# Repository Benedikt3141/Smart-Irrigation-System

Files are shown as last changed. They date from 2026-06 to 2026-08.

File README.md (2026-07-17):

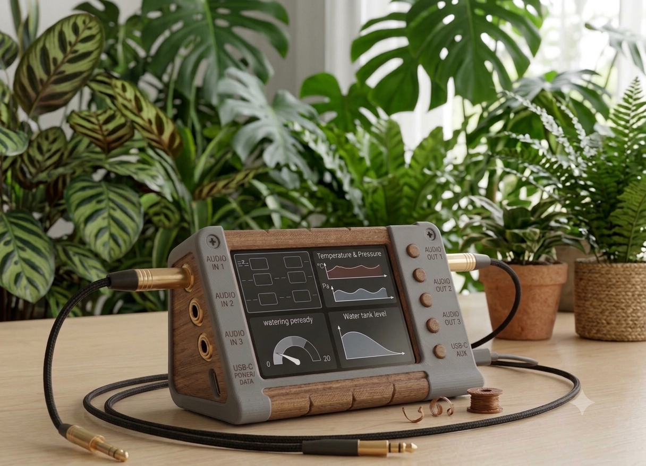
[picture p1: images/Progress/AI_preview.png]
AIPreview


-> AI Preview

# Smart Irrigation System

The Smart Irrigation System is a battery-powered monitoring and control system for watering up to six individual plants.
Each plant is monitored by a capacitive soil moisture sensor connected to the main control unit.

The project currently focuses on the main monitoring and control unit. A separate watering unit is planned but not fully designed yet. Communication between both units is intended to use ESP-NOW.

## Project Overview

The system consists of two main parts:

### Main Monitoring and Control Unit

The main unit collects sensor data, displays current measurements on a TFT screen, logs data to an SD card and indicates the system status using an LED strip.

Each soil moisture sensor is connected individually using an audio jack connector.

### Watering Unit

The watering unit is planned as a separate module. It will receive commands from the main control unit via ESP-NOW and control the water flow using a solenoid valve.
The unit should also monitor the water tank level using an ultrasonic sensor.

This part of the system is still work in progress.

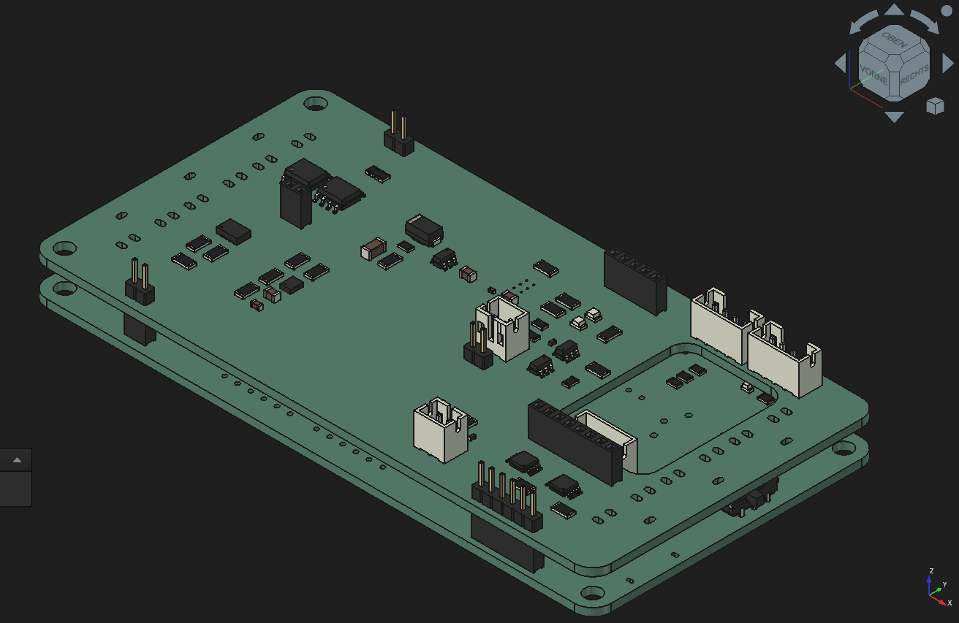
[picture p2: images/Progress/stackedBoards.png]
stackedBoards


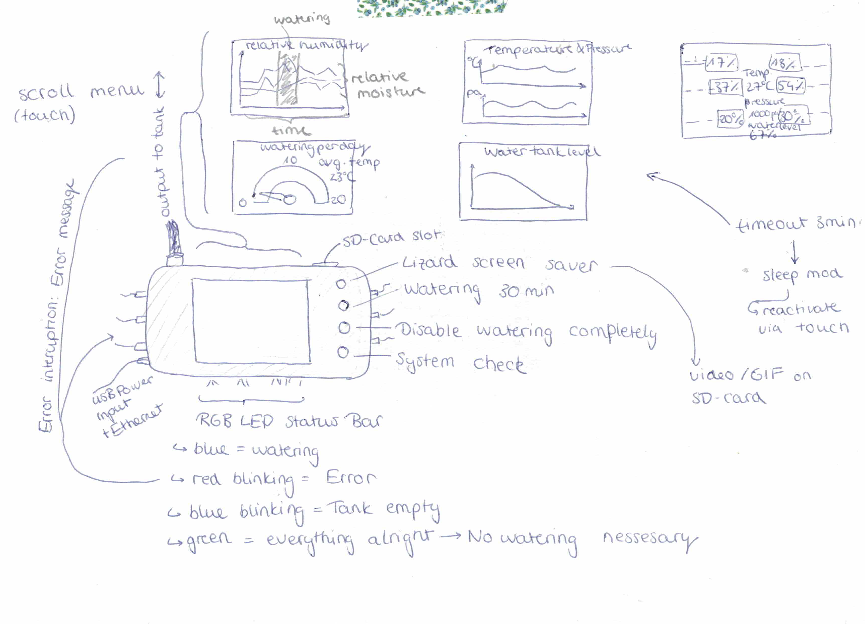
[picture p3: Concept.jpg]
Concept


## Feature overview

###### Sensors (Inputs)

- **Soil mositure monitoring** for individual plants
- **Temperature**
- Humidity
- Air pressure
- Air Quality
- CO2 concentration
- Solar intensity
- 4 Buttons
- *Tank fill state sensor*

###### Other features and outputs

- **Battery powered**
- 2.4" TFT LCD Screen with resistive touch
- SD log with data saved as .csv
- LED-Strip status indicator
- magnetic valve for watering Control
- *web interface*
- *Push Emails when water is empty/error etc.*

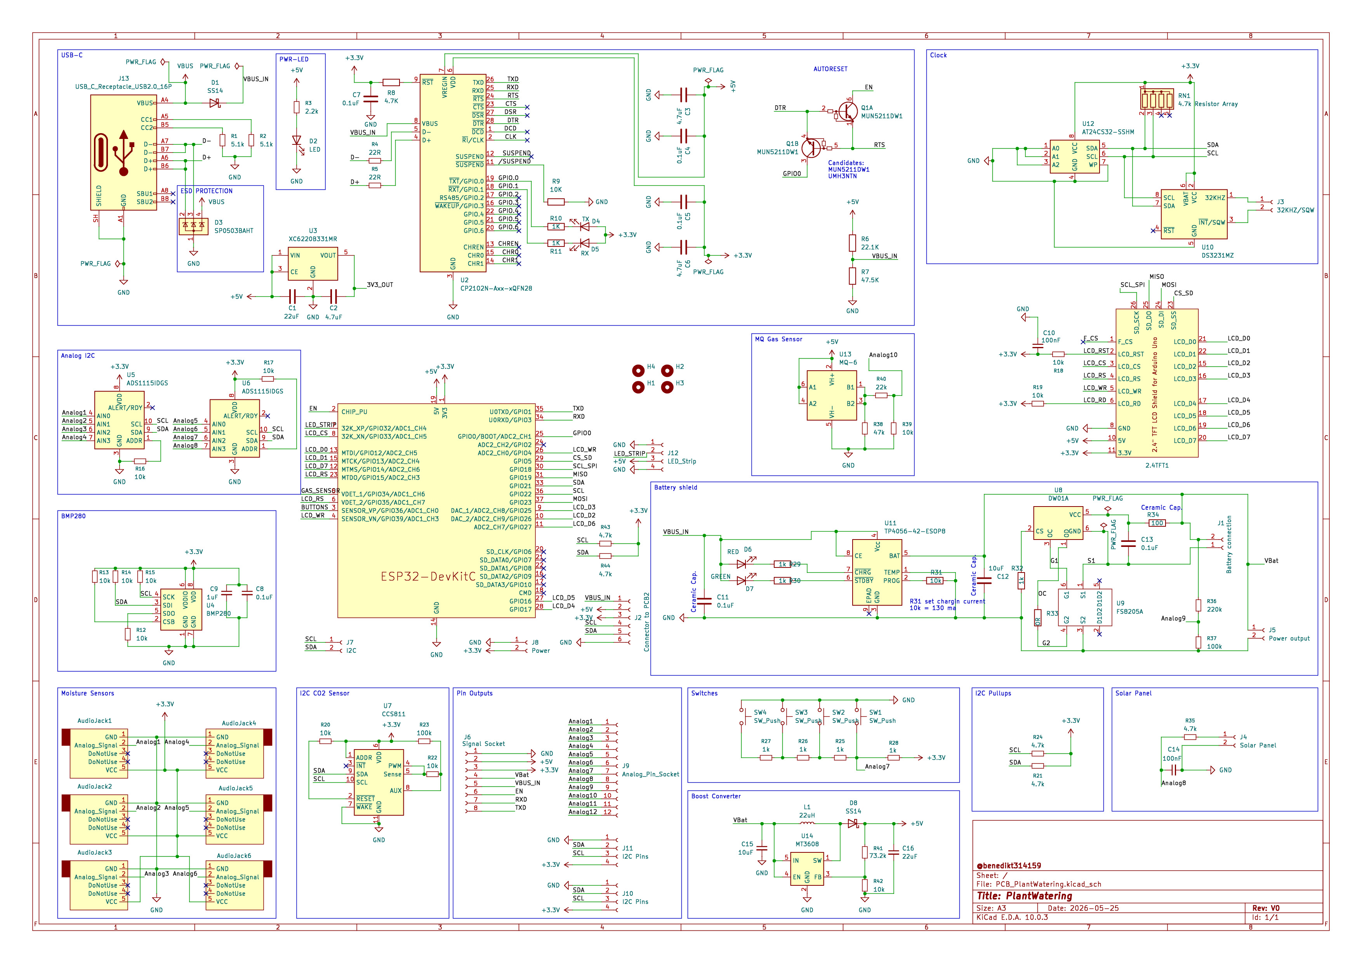
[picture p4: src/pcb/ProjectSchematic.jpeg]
Schematic


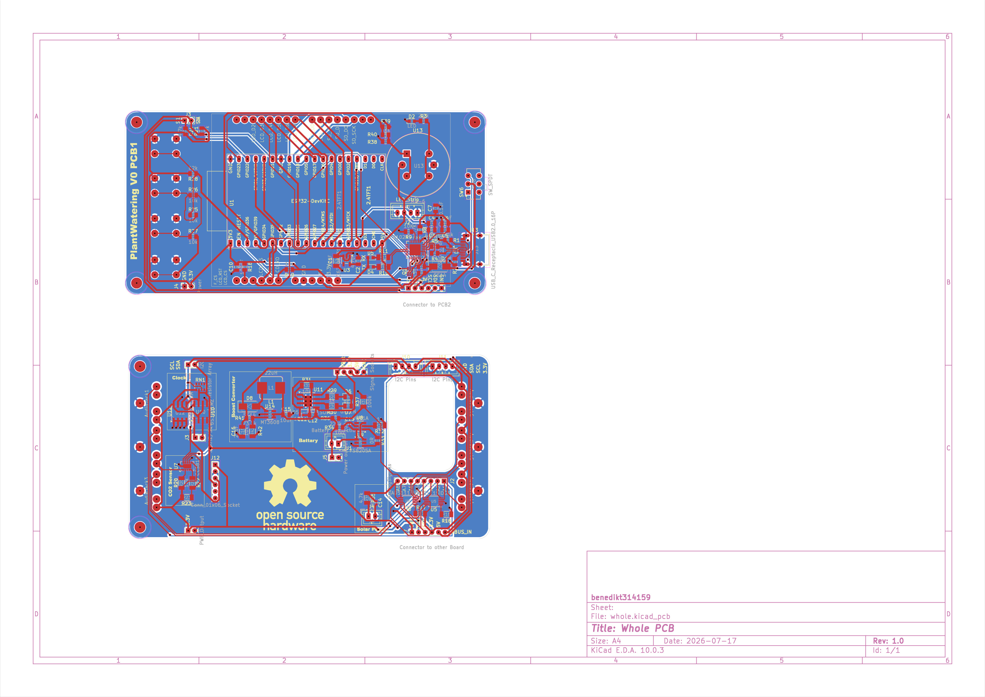
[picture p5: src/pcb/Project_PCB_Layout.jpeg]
PCB


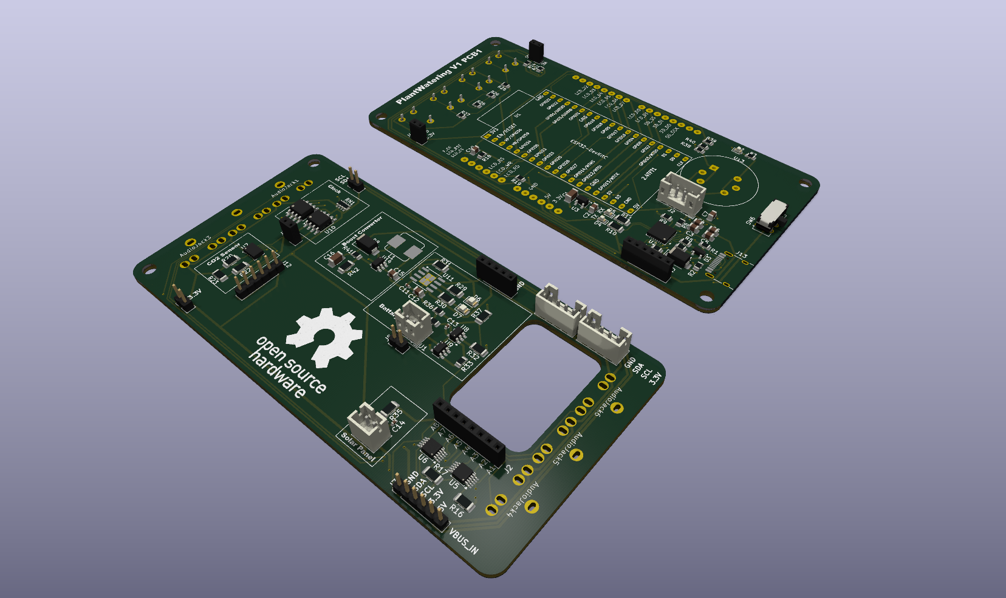
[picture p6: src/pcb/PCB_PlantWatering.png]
Rendering


## Repository Structure

This repository contains both the firmware and the PCB design files.

- `/firmware/` contains the PlatformIO firmware project.
- `/firmware/src/` contains the ESP32 source code.
- `/src/pcb/` contains the KiCad PCB design files.
- `/src/pcb/gerbers/` contains the exported Gerber files for manufacturing.

The main monitoring and control unit consists of two stacked custom PCBs. Both PCBs are part of the same project and are required for the complete device.

## File Structure

```
Smart-Irrigation-System/
├── BOM.csv
├── JOURNAL.md
├── README.md
├── firmware/
│   ├── platformio.ini
│   └── src/
├── src/
│   ├── assembly_and_models/
│   │   ├── SmartIrrigationSystem-Assembly.step
│   │   └── SmartIrrigationSystem.FCStd
│   └── pcb/
│       ├── PlantWatering_PCB01/
│       ├── PlantWatering_PCB02/
│       └── gerbers/
└── images/
```

## Getting started

#### Requirements

To work with this project, you need:

* VS Code
* PlatformIO or pioarduino IDE Extension
* C++ Compiler
* KiCad 10.0.1 or later

#### Installation

Use git to clone this repository into your computer.

```
git clone https://github.com/Benedikt3141/Smart-Irrigation-System.git
```

Open the project folder in VS Code and build/upload the firmware using PlatformIO or pioarduino.

###### Hardware

You can either use the provided Gerber files or modify the KiCad project and generate new manufacturing files for your preferred PCB supplier.

You can find the gerberfiles [here (PCB01)](src/pcb/PlantWatering_PCB01/production) and [here (PCB02)](src/pcb/PlantWatering_PCB02/production)) or in the project root. The correlating `BOM.csv` and `position.csv` can be found in the same directories.

## License

[MIT](https://choosealicense.com/licenses/mit/)

## Current Project Status

This project is still in development.

The main monitoring unit is mostly implemented. The watering unit, web interface and notification system are planned but not finished yet.

## Sources

[MQ2 Library](https://github.com/labay11/MQ-2-sensor-library/)
[SD Card](https://RandomNerdTutorials.com/esp32-web-server-microsd-card/)

## AI Usage

Most of the code was written by myself. Since this is a work in progress, the code may still contain bugs or parts that could be improved.

I used AI for debugging assistance, spelling correction, research and for generating the concept visualization shown at the top of this README.

The visualization is intended only as a preview of the planned device and
does not represent the final manufactured hardware.

The PCB design, hardware architecture and most of the firmware were
created by myself.

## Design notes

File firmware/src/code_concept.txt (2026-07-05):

setup {
    selfcheck <-- Output auf Display
        initialization and startup of all objects
            Display
            SD Card
            Soil moisture
            etc. 
        I2C addresses ar working?
        reasonable values of sensors?

        else: Errorhandling
    wifi initialization
    web server initialization
}

loop {
    is button interrupt/ timer clock etc.
        get Values and log to .csv/ do task

        plot graphs --> only if asked for
        show plots
}

todo: reset/pwr off button/switch to PCB02

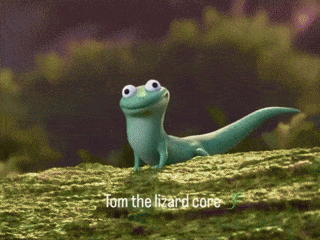
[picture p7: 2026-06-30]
firmware/images/Lizard/Lizard.gif

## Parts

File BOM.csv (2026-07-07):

Item Name | Qty | Price (total) (USD) | Item link | Notes
PlantWatering_PCB02 — bare PCB fabrication | 5 | 8.78 | https://jlcpcb.com/ | 5 bare PCB02 boards; required as one half of the stacked Main Monitoring and Control Unit. Cart item: PlantWatering_PCB02_Y4. Original cart amount: EUR 7.68. Converted using ECB 2026-07-07 reference rate EUR 1 = USD 1.1433.
PlantWatering_PCB02 — PCBA assembly | 2 | 113.05 | https://jlcpcb.com/ | 2 assembled PCB02 units, top-side assembly. Current cart quantity differs from PCB01; verify that this is intentional before submission. Original cart amount: EUR 98.88. Converted using ECB 2026-07-07 reference rate EUR 1 = USD 1.1433. | Only two assembled PCB02 units are required because this board is less exposed during assembly and normal use.
PlantWatering_PCB01 — bare PCB fabrication | 5 | 7.89 | https://jlcpcb.com/ | 5 bare PCB01 boards; required as the second half of the stacked Main Monitoring and Control Unit. Cart item: PlantWatering_PCB01_V1_Y3. Original cart amount: EUR 6.90. Converted using ECB 2026-07-07 reference rate EUR 1 = USD 1.1433.
PlantWatering_PCB01 — PCBA assembly | 5 | 54.64 | https://jlcpcb.com/ | 5 assembled PCB01 units, top-side assembly. Current cart quantity differs from PCB02; verify that this is intentional before submission. Original cart amount: EUR 47.79. Converted using ECB 2026-07-07 reference rate EUR 1 = USD 1.1433. | More reliable. This is the module that will break more likely
Estimated shipping | 1 | 23.38 | https://jlcpcb.com/ | Estimated shipping shown in the current JLCPCB cart screenshot. Original cart amount: EUR 20.45. Converted using ECB 2026-07-07 reference rate EUR 1 = USD 1.1433.
JLCPCB coupon | 1 | -19.96 | https://jlcpcb.com/ | Current cart discount; entered as a negative line item so the BOM total matches the cart subtotal. Original cart amount: EUR -17.46. Converted using ECB 2026-07-07 reference rate EUR 1 = USD 1.1433.
Total Price |  | 187.78 |  | Current cart subtotal converted to USD at ECB 2026-07-07 reference rate.

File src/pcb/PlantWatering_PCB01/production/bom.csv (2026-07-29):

Reference | Qty | Value | DNP | Exclude from BOM | Exclude from Board | Footprint | LCSC PN
C1 | 1 | 22uF |  |  |  | Capacitor_SMD:C_1206_3216Metric | C5672
C2,C3,C6 | 3 | 4.7uF |  |  |  | Capacitor_SMD:C_0805_2012Metric | C1779
C4,C5,C7 | 3 | 0.1uF |  |  |  | Capacitor_SMD:C_0805_2012Metric | C28233
C10 | 1 | 100nF |  |  |  | Capacitor_SMD:C_0805_2012Metric | C28233
D1 | 1 | SS14 |  |  |  | Diode_SMD:D_SMA | C2480
D2 | 1 | LED |  |  |  | LED_SMD:LED_0603_1608Metric | C2286
D3 | 1 | SP0503BAHT |  |  |  | Package_TO_SOT_SMD:SOT-143 | C2682275
D4 | 1 | TX |  |  |  | LED_SMD:LED_0603_1608Metric | C2286
D5 | 1 | RX |  |  |  | LED_SMD:LED_0603_1608Metric | C2286
J13 | 1 | USB_C_Receptacle_USB2.0_16P |  |  |  | Connector_USB:USB_C_Receptacle_HRO_TYPE-C-31-M-12 | C5337088
Q1 | 1 | MUN5211DW1 |  |  |  | Package_TO_SOT_SMD:SOT-363_SC-70-6 | C152507
R1,R2 | 2 | 5.1k |  |  |  | Resistor_SMD:R_0805_2012Metric | C27834
R3 | 1 | 2.2k |  |  |  | Resistor_SMD:R_0805_2012Metric | C17520
R4,R5 | 2 | 22R |  |  |  | Resistor_SMD:R_0805_2012Metric | C17561
R6 | 1 | 22.1K |  |  |  | Resistor_SMD:R_0805_2012Metric | C17552
R7 | 1 | 47.5K |  |  |  | Resistor_SMD:R_0805_2012Metric | C26011
R8 | 1 | 4.7K |  |  |  | Resistor_SMD:R_0805_2012Metric | C17673
R9 | 1 | 10K |  |  |  | Resistor_SMD:R_0805_2012Metric | C17414
R10,R11 | 2 | 1K |  |  |  | Resistor_SMD:R_1206_3216Metric | C1469
R18,R19,R25,R26,R27,R39 | 6 | 10k |  |  |  | Resistor_SMD:R_0805_2012Metric | C17414
R21,R24 | 2 | 4.7k |  |  |  | Resistor_SMD:R_0805_2012Metric | C17673
R28 | 1 | 62k |  |  |  | Resistor_SMD:R_0805_2012Metric | C17783
R38 | 1 | 47k |  |  |  | Resistor_SMD:R_0805_2012Metric | C17713
R40 | 1 | 22k |  |  |  | Resistor_SMD:R_0805_2012Metric | C17560
SW6 | 1 | SW_SPDT |  |  |  | Button_Switch_THT:SW_CK_JS202011AQN_DPDT_Angled | C221662
U2 | 1 | CP2102N-Axx-xQFN24 |  |  |  | Package_DFN_QFN:QFN-28-QFN-24-EP(4x4) | C969151
U3 | 1 | XC6220B331MR |  |  |  | Package_TO_SOT_SMD:SOT-23-5 | C22466451

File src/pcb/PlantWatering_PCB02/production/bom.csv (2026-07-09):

Reference | Qty | Value | DNP | Exclude from BOM | Exclude from Board | Footprint | LCSC PN
AudioJack1,AudioJack2,AudioJack3,AudioJack4,AudioJack5,AudioJack6 | 6 |  |  |  |  | ESP32_NodeMCU:PJ-3126-5A | C145816
C11,C13,C14 | 3 | 100nF |  |  |  | Capacitor_SMD:C_0402_1005Metric | C1525
C12,C15 | 2 | 10uF |  |  |  | Capacitor_SMD:C_0805_2012Metric | C1713
C16 | 1 | 22uF |  |  |  | Capacitor_SMD:C_1206_3216Metric | C5672
D6 | 1 | RED |  |  |  | LED_SMD:LED_0805_2012Metric | C84256
D7 | 1 | GREEN |  |  |  | LED_SMD:LED_0805_2012Metric | C84260
D8 | 1 | SS14 |  |  |  | Diode_SMD:D_SMA | C2480
L1 | 1 | 22uH |  |  |  | Inductor_SMD:L_Bourns_SRP7028A_7.3x6.6mm | C2838326
R16,R17,R20,R22,R31,R42 | 6 | 10k |  |  |  | Resistor_SMD:R_1206_3216Metric | C1489
R23,R37 | 2 | 100k |  |  |  | Resistor_SMD:R_1206_3216Metric | C17900
R29,R30,R32 | 3 | 1k |  |  |  | Resistor_SMD:R_1206_3216Metric | C4410
R33 | 1 | 0R |  |  |  | Resistor_SMD:R_0805_2012Metric | C17477
R34 | 1 | 100 |  |  |  | Resistor_SMD:R_0805_2012Metric | C17408
R35 | 1 | 4.7k |  |  |  | Resistor_SMD:R_1206_3216Metric | C17936
R36 | 1 | 220k |  |  |  | Resistor_SMD:R_0805_2012Metric | C17556
R41 | 1 | 73.2k |  |  |  | Resistor_SMD:R_0805_2012Metric | C17814
RN1 | 1 | 4.7k Resistor Array |  |  |  | Resistor_SMD:R_Array_Convex_4x0603 | C1980
U5,U6 | 2 | ADS1115IDGS |  |  |  | Package_SO:TSSOP-10_3x3mm_P0.5mm | C37593
U8 | 1 | DW01A |  |  |  | Package_TO_SOT_SMD:SOT-23-6 | C351410
U9 | 1 | FS8205A |  |  |  | Package_TO_SOT_SMD:SOT-23-6 | C908265
U10 | 1 | DS3231MZ |  |  |  | Package_SO:SOIC-8_3.9x4.9mm_P1.27mm | C107410
U11 | 1 | TP4056-42-ESOP8 |  |  |  | Package_SO:SOIC-8-1EP_3.9x4.9mm_P1.27mm_EP2.41x3.3mm_ThermalVias | C16581
U12 | 1 | AT24CS32-SSHM |  |  |  | Package_SO:SOIC-8_3.9x4.9mm_P1.27mm | C615972
U14 | 1 | MT3608 |  |  |  | Package_TO_SOT_SMD:SOT-23-6 | C84817

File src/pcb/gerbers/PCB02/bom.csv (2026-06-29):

Designator | Footprint | Quantity | Value | LCSC Part #
AUDIOJACK1, AUDIOJACK2, AUDIOJACK3, AUDIOJACK4, AUDIOJACK5, AUDIOJACK6 | PJ-3126-5A | 6 | ~ | C145816
C11, C13, C14 | 0402 | 3 | 100nF | C1525
C12, C15 | 0805 | 2 | 10uF | C1713
C16 | 1206 | 1 | 22uF | C5672
C8 | 0805 | 1 | 0.1uF | C1711
C9 | 0603 | 1 | 1uF | C1592
D6 | 0805 | 1 | RED | C84256
D7 | 0805 | 1 | GREEN | C84260
D8 | D_SMA | 1 | SS14 | C2480
L1 | L_Bourns_SRP7028A_7.3x6.6mm | 1 | 22uH | C2838326
R12, R13, R14, R15, R16, R17, R31, R42 | 1206 | 8 | 10k | C1489
R20, R22 | 1206 | 2 | 10k
R23 | 1206 | 1 | 100k
R29, R30, R32 | 1206 | 3 | 1k | C4410
R33 | 0805 | 1 | 0R | C17477
R34 | 0805 | 1 | 100 | C17408
R35 | 1206 | 1 | 4.7k | C17936
R36 | 0805 | 1 | 220k | C17556
R37 | 1206 | 1 | 100k | C17900
R41 | 0805 | 1 | 73.2k | C17814
RN1 | R_Array_Convex_4x0603 | 1 | 4.7k Resistor Array | C1980
U10 | SOIC-8_3.9x4.9mm_P1.27mm | 1 | DS3231MZ | C107410
U11 | SOIC-8-1EP_3.9x4.9mm_P1.27mm_EP2.41x3.3mm_ThermalVias | 1 | TP4056-42-ESOP8 | C16581
U12 | SOIC-8_3.9x4.9mm_P1.27mm | 1 | AT24CS32-SSHM | C615972
U14 | SOT-23-6 | 1 | MT3608 | C84817
U4 | Bosch_LGA-8_2x2.5mm_P0.65mm_ClockwisePinNumbering | 1 | BMP280 | C83291
U5, U6 | TSSOP-10_3x3mm_P0.5mm | 2 | ADS1115IDGS | C37593
U7 | AMS_LGA-10-1EP_2.7x4mm_P0.6mm | 1 | CCS811
U8 | SOT-23-6 | 1 | DW01A | C351410
U9 | SOT-23-6 | 1 | FS8205A | C908265

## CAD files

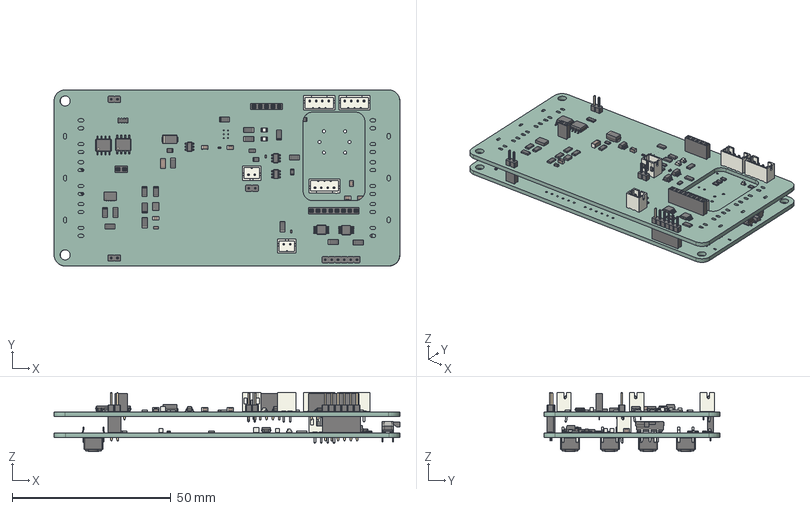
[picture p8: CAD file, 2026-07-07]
src/assembly_and_models/SmartIrrigationSystem-Assembly.step
109.1 x 55.5 x 18.6 mm
SW_CuK_JS202011AQN_DPDT_Angled
R_0805_2012Metric008 x 18
R_1206_3216Metric032 x 4
LED_0603_1608Metric x 3
PinSocket_1x06_P2.00mm_Vertical
PinSocket_1x02_P2.00mm_Vertical002 x 2
C_0805_2012Metric006 x 7
JST_B4B_PH_K002
C_1206_3216Metric002
SOT-23-5
D_SMA002
QFN-28-1EP_5x5mm_Pitch0.5mm
SOT-143
SOT-363_SC-70-6
SW_PUSH_6mm x 4
PlantWatering_PCB01_PCB
LED_0805_2012Metric x 2
PinSocket_1x05_P2.00mm_Vertical
R_0805_2012Metric x 4
SOIC-8_3.9x4.9mm_P1.27mm x 2
R_1206_3216Metric x 16
PinHeader_1x06_P200mm_Vertical
JST_B4B_PH_K x 2
SOT-23-6 x 3
C_0805_2012Metric x 3
JST_B2B_PH_K x 2
PinHeader_1x02_P200mm_Vertical x 3
C_1206_3216Metric
Bosch_LGA_8_2x25mm_P065mm_ClockwisePinNumbering
R_Array_Convex_4x0603
C_0402_1005Metric x 3
D_SMA
PinSocket_1x02_P2.00mm_Vertical
AMS_LGA_10_1EP_27x4mm_P06mm
PinSocket_1x08_P2.00mm_Vertical
TSSOP-10_3x3mm_P0.5mm x 2
C_0603_1608Metric
PlantWatering_PCB02_PCB

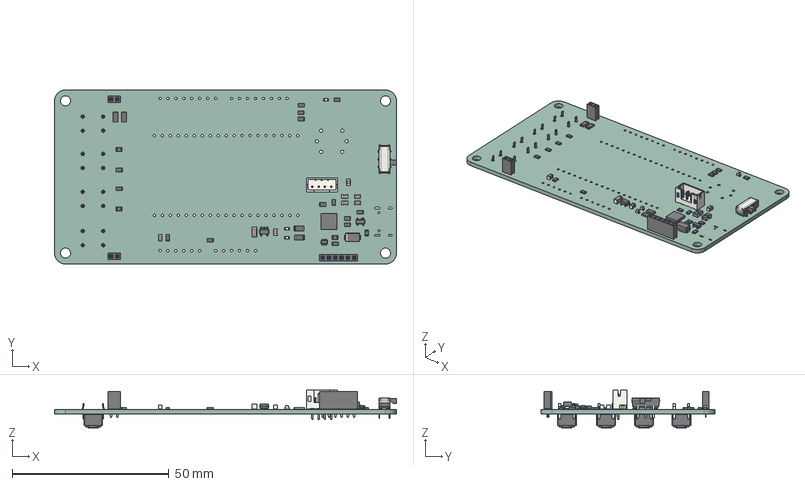
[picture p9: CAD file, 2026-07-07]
src/pcb/PlantWatering_PCB01/PCB01.step
109.0 x 55.5 x 12.0 mm
SW_CuK_JS202011AQN_DPDT_Angled
R_0805_2012Metric x 18
R_1206_3216Metric x 4
LED_0603_1608Metric x 3
PinSocket_1x06_P2.00mm_Vertical
PinSocket_1x02_P2.00mm_Vertical x 2
C_0805_2012Metric x 7
JST_B4B_PH_K
C_1206_3216Metric
SOT-23-5
D_SMA
QFN-28-1EP_5x5mm_Pitch0.5mm
SOT-143
SOT-363_SC-70-6
SW_PUSH_6mm x 4
PlantWatering_PCB01_PCB

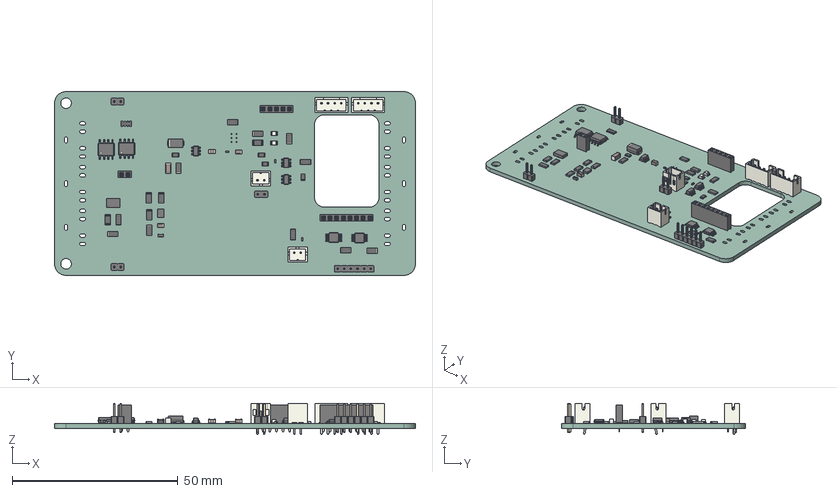
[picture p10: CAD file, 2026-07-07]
src/pcb/PlantWatering_PCB02/PCB02.step
109.0 x 55.5 x 9.40 mm
LED_0805_2012Metric x 2
PinSocket_1x05_P2.00mm_Vertical
R_0805_2012Metric x 4
SOIC-8_3.9x4.9mm_P1.27mm x 2
R_1206_3216Metric x 16
PinHeader_1x06_P200mm_Vertical
JST_B4B_PH_K x 2
SOT-23-6 x 3
C_0805_2012Metric x 3
JST_B2B_PH_K x 2
PinHeader_1x02_P200mm_Vertical x 3
C_1206_3216Metric
Bosch_LGA_8_2x25mm_P065mm_ClockwisePinNumbering
R_Array_Convex_4x0603
C_0402_1005Metric x 3
D_SMA
PinSocket_1x02_P2.00mm_Vertical
AMS_LGA_10_1EP_27x4mm_P06mm
PinSocket_1x08_P2.00mm_Vertical
TSSOP-10_3x3mm_P0.5mm x 2
C_0603_1608Metric
PlantWatering_PCB02_PCB

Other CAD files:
src/assembly_and_models/SmartIrrigationSystem.FCStd

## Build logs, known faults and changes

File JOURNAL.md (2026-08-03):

---
Title: "Smart Irrigation System"
Author: "Benedikt 314159" 
Description: "A monitoring and control unit of a smart irrigation system with soil moisture sensors, environmental sensors, display, buttons and SD logging."
Created On: "13/04/2026"
---

# Journal

## April 2026

I looked for possible solutions for my idea of a smart irrigation system and searched for existing repositories. However, nothing really fitted my needs, so I decided to build my own system.

I researched the required hardware and learned how capacitive soil moisture sensors work. I also started thinking about how the system could monitor several plants individually and how the data could later be used for automatic watering.

**Time spent:** \~5 h

\---

## End of April 2026

I ordered my first soil moisture sensors and tried to monitor soil moisture with an ESP32 DevKitC. I had some issues when using Wi-Fi and analog readings at the same time on the ESP32. I had to figure out which analog pins were still available while Wi-Fi was enabled and which six pins I could use for the sensors.

I coded the first basic working version of the system and designed a simple but good-looking web interface. For that, I had to revise my HTML skills, which were not very strong at that point. I also had to decide which file format I wanted to use for the database. I chose `.csv` because it is much more lightweight than SQL or JSON databases. I had also worked with `.csv` files before, so it was easier for me to get started and modify them using C++ on the ESP32.

I could not find a good existing library or code example that fitted my use case, so I had to code the CSV logging functionality from scratch.

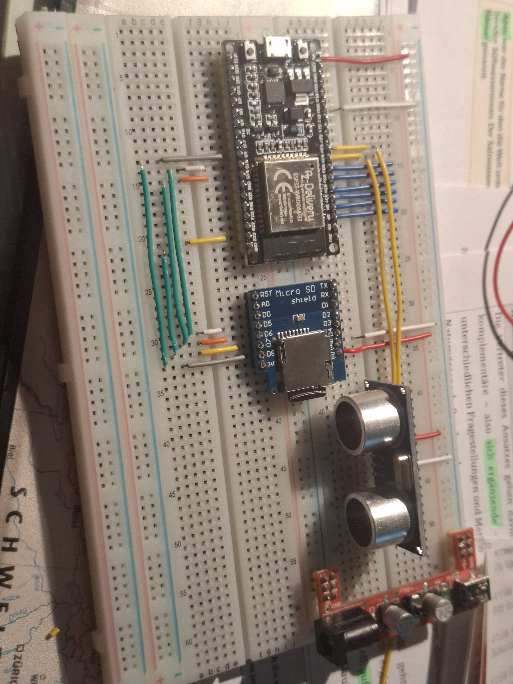
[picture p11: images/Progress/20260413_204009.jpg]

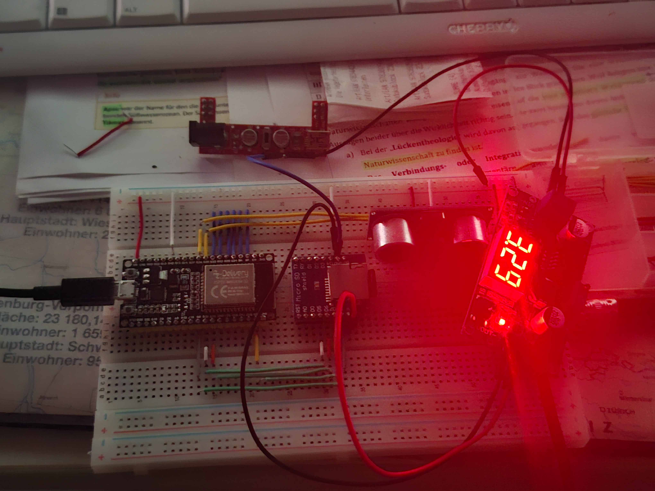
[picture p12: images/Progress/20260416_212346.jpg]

↑ Images of the first conceptional breadboard setup

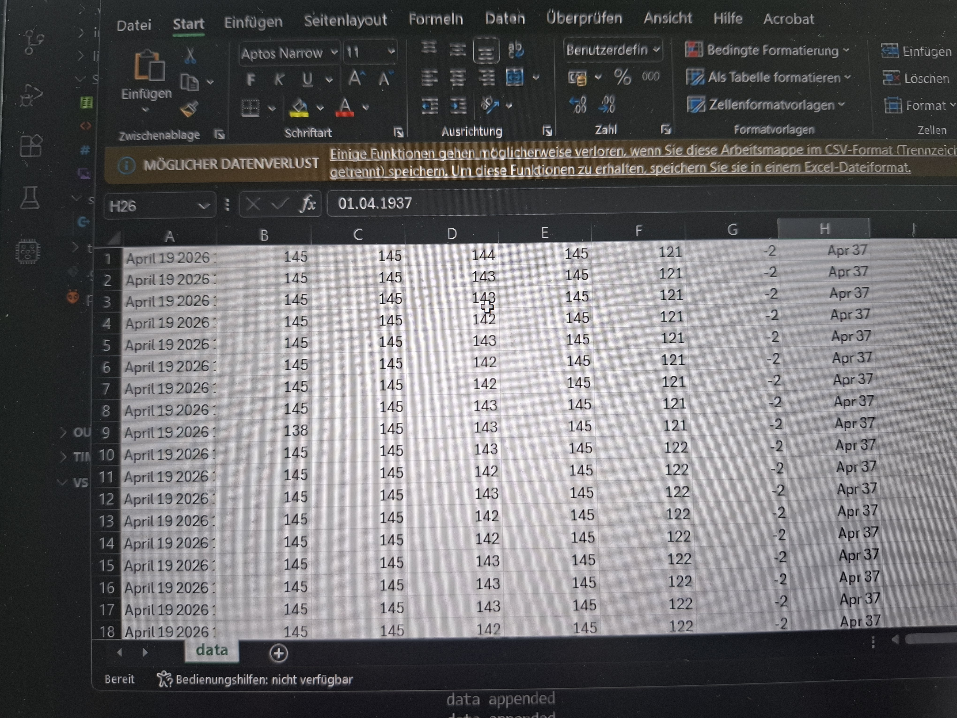
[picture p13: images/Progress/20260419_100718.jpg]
firstData

↑ this was the first data set I catured with the sensors and is captured as a `.csv` file

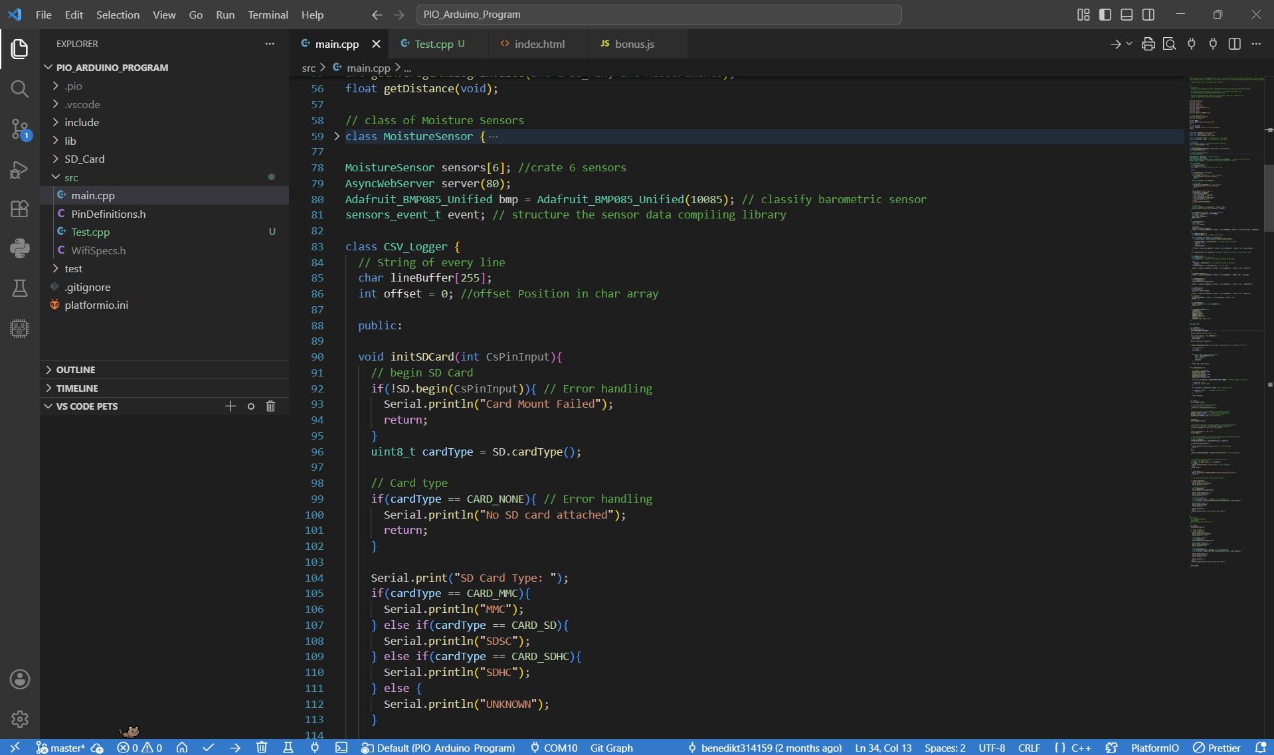
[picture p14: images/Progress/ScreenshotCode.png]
firstCode

↑ Screenshot of the code. Look at full code [here](images/Progress/main_cpp_old.pdf)

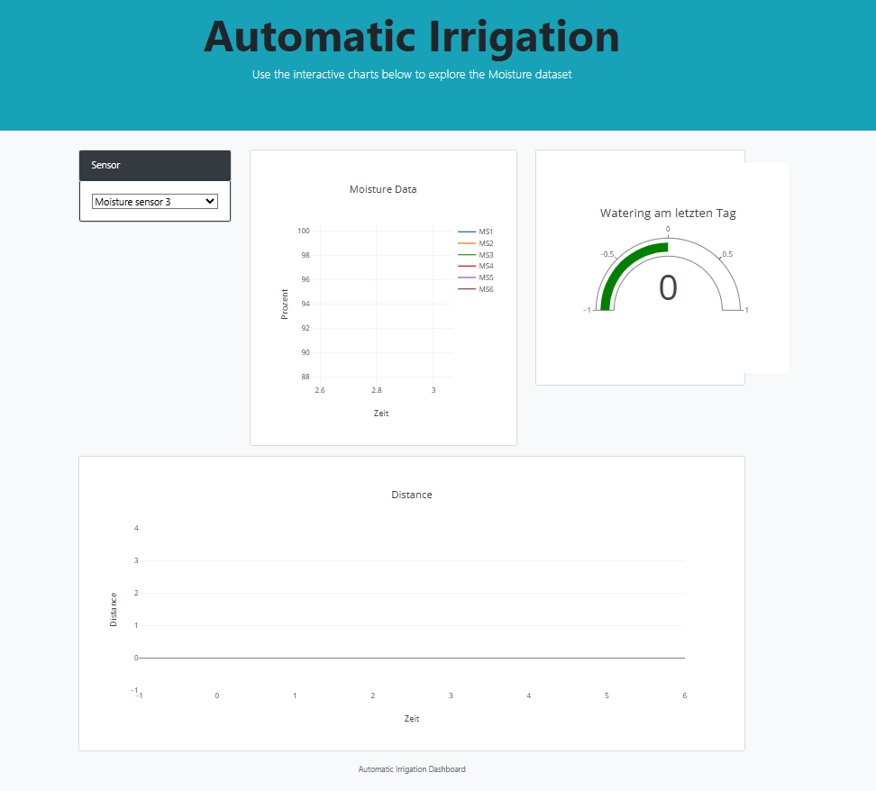
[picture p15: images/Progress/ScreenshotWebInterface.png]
firstWebInterface

↑ first WebInteface (already working!!!)

**Time spent:** \~8 h

\---

## Beginning of May 2026

I decided to add a display as an addition to the web interface and ordered a 2.4" TFT LCD screen with resistive touch. However, the display I ordered was especially designed for an Arduino Uno R3 or compatible boards.

Because of that, I had to decide whether I should order a different display, connect the display directly to the ESP32 with wires and lose many of its GPIOs, or connect the Arduino to the ESP32 using some kind of communication protocol.

I researched different kinds of buses and the capabilities of the built-in chip of the Arduino Uno. I came to the conclusion that no bus would be really suitable for transferring a decent amount of display data reliably and fast enough with the Arduino Uno. The Arduino processor would also be too weak for processing diagrams smoothly. Therefore, the diagrams would have to be processed on the ESP32 before being transferred, which would make the system unnecessarily complicated.

In the end, I decided to wire the display directly to the ESP32 and accept the reduced number of free GPIOs.

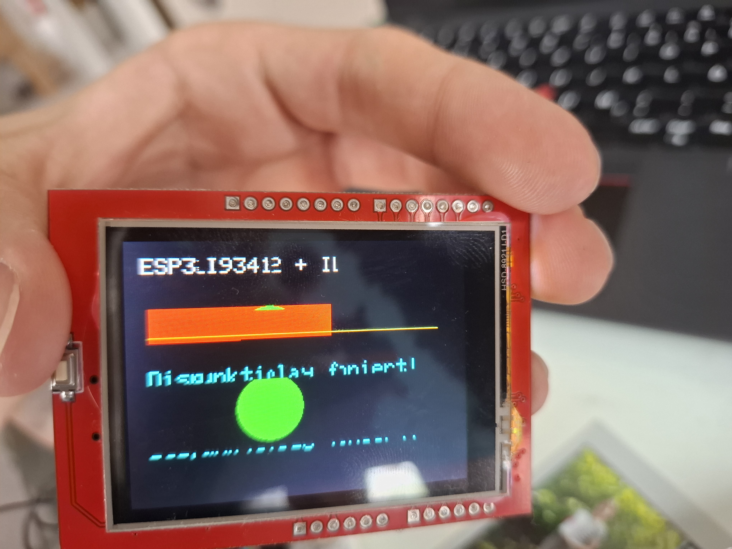
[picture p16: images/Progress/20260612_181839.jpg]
DisplayTest

↑ First Image on Display. There were still errors like you can see :(

**Time spent:** \~6 h
This included trial and error, research and consideration of different possible solutions.

\---

## May 2026 until begin of June 2026

*20.05., 28.05., 05.06., 12.06. and dates between*

At this point, I first had to clearly define the goals of the project because I kept getting more and more ideas. I considered adding a battery, a USB-C connection, many different sensors, a small solar panel and several other useful or less useful ideas.

To organize the project, I drew a concept diagram and wrote down which GPIO pin should be used for which device. This took longer than expected because some ESP32 pins were not actually capable of doing what I wanted to use them for. There was also still a lack of analog input pins, so I found an I2C analog input expander and ordered it for breadboard testing.

Besides the breadboard prototype, I wanted to build the system as a solid PCB. I researched different PCB design programs and chose KiCad as my preferred PCB design software. I had to get used to the basic principles of PCB design, the general PCB design workflow and some unusual traits of KiCad.

This also took much longer than I had expected. By the end of May 2026, I started designing the PCB for the project. During the PCB design process, I realized that the proportions I had imagined did not really fit reality. Because of that, I decided to split the PCB of the main unit into separate PCBs that could be stacked on top of each other.

At first, I designed the boards as 4-layer PCBs because that made routing much easier than on a 2-layer PCB and I did not have to worry as much about component orientation and trace routing. Later, I changed the design to a 2-layer PCB because it is much cheaper to manufacture.

In addition, I decided to use JLCPCB for PCB manufacturing and researched suitable components. This was quite complex for me because I had not worked much with the specific features of PCB components before. Until then, I had mostly used breadboard modules, through-hole resistors, capacitors, diodes and single-wire- or analog-sensors.

By the end of May, I had created the first PCB design. However, I realized that manufacturing both boards would be much too expensive, around 250 €, so I decided to focus more on the code for a while and postpone the hardware order.

This whole process of getting used to PCB design software, making first attempts, failing, fixing problems and finally achieving some progress took a long time. I did not track the time exactly, but it must have taken much more than 20 hours.

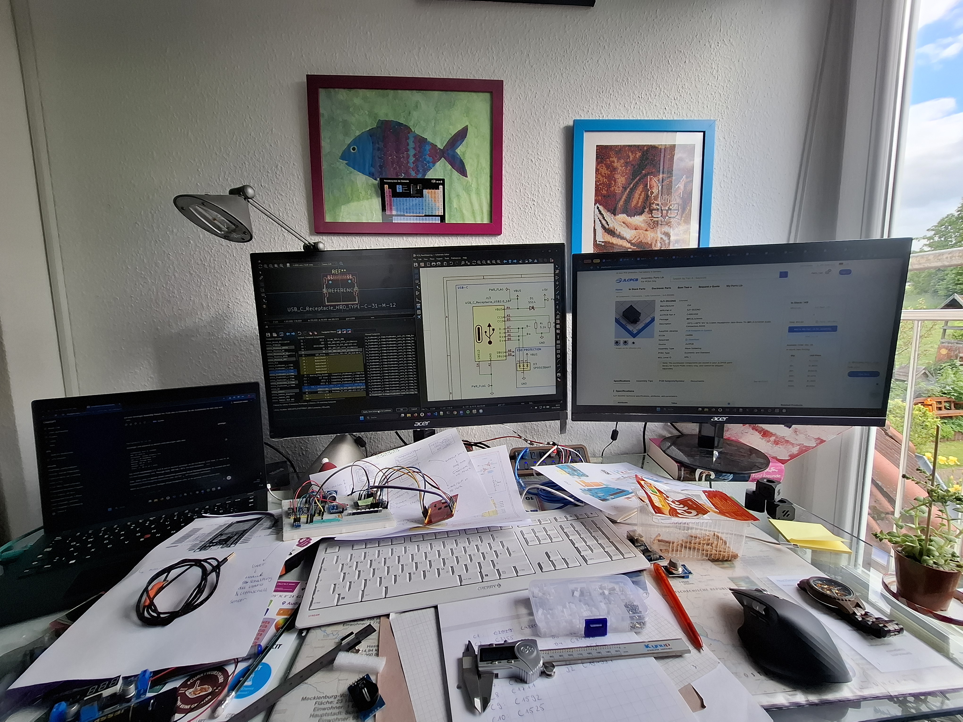
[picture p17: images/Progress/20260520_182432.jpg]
KicadSetup

↑ My KiCAD designing setup :)

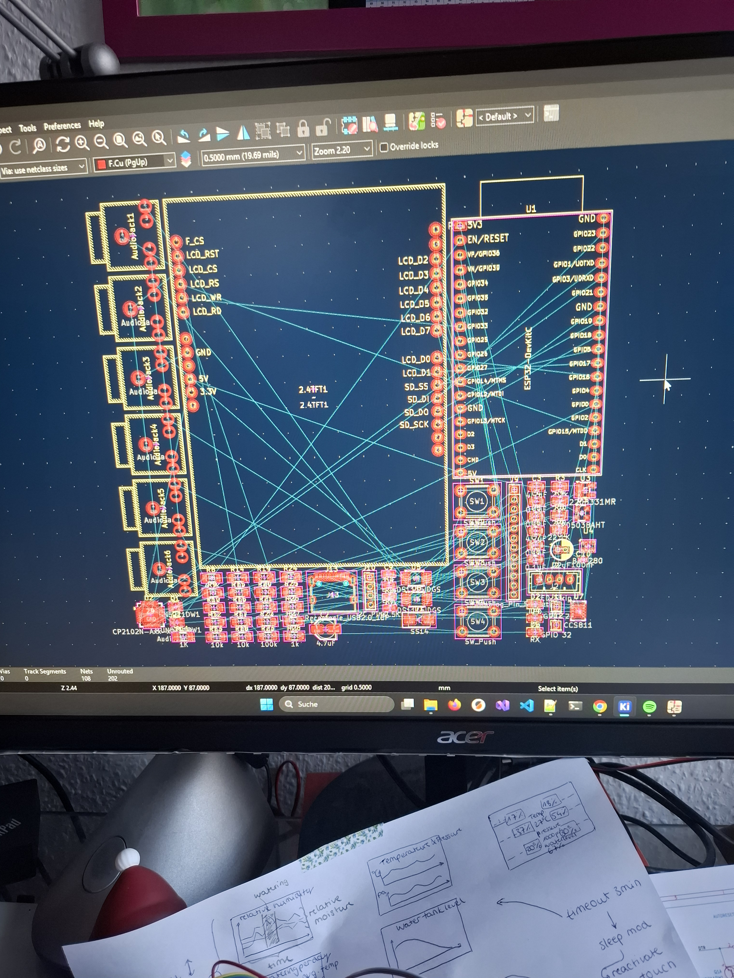
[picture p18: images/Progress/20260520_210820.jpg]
PCBSetup

↑ First time switching to PCB workbench with this project in KiCAD

**Time spent:** >20 h

\---

## June 2026

After the disappointment with the first PCB design, I focused more on the code for the project. I mounted the modules on a breadboard and tested the wiring of the components. During testing, I found some errors in my wiring configuration. I fixed these issues and tested almost every part of the board.

The display was still much more complicated than the other parts. I also had to revise different bus types in order to understand the communication of the 8-bit display, the I2C sensors and the SPI SD shield.

In addition, I ran into some issues with the analog button wiring, so I had to test different kinds of pull-up resistors until it finally worked.

I modified the schematic of the PCB according to these changes and also completely redesigned the PCB layout as a two-layer board (I actually had to do it twice because I forgot to save my changes). This should save about 100 € in manufacturing costs compared to the previous design.

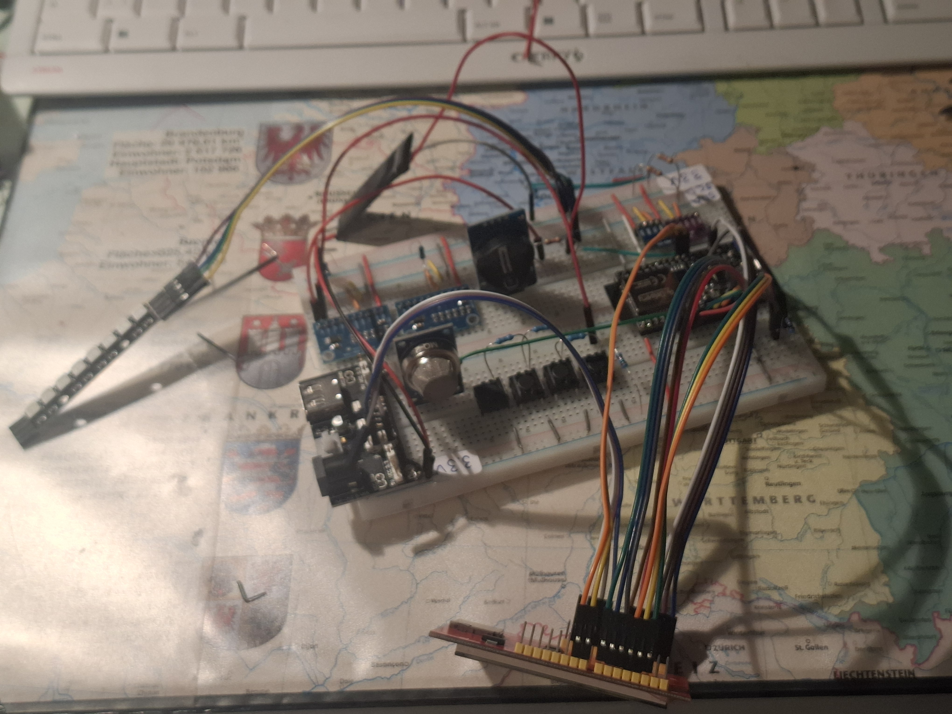
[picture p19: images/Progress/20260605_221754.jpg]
breadboard

↑ The breadboard looked like this from that on

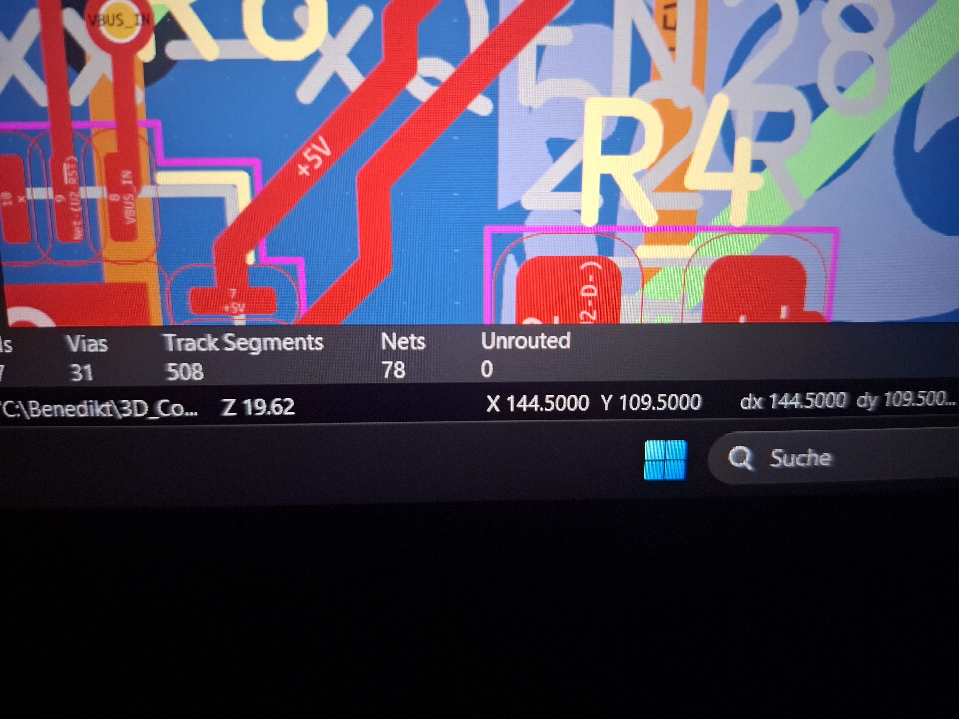
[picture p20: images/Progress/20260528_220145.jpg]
KiCAD

↑ Another photo of me editing something in KiCAD

Time spent: ~12 h

---

## June 30, 2026

I worked on the screensaver feature. For this, I downloaded a short TikTok video as an `.mp4` file and converted it into a `.gif` file using an online converter. I was then able to process this file with a desktop program and convert it into an `.mjpeg` file, which could be read by the ESP32.

I had to do a lot of research to find a suitable system for decoding and playing a video from an SD card on the ESP32. After several tests and adjustments, the lizard video now looks amazing and is exactly what I was looking for. Additionally, everything is already prepared for implementing screensaver interrupts later.

[LizardVideo](images/Progress/20260630_183828.mp4)
↑ I got it!

**Time spent:** ~5 h

## July 2026

After asking in the Hack Club hardware channel, I learned that I can submit both PCBs because they belong to the same project. I reorganized the repository by moving the PlatformIO firmware into `/firmware` and creating a separate `/pcb` folder for the KiCad files and Gerber exports. I also added some features and improved the PCB to the final design. Now everything shold be working fine...

Time spent: ~6 h

## July 6/7, 2026

I prepared the mechanical files for the final submission. I exported both
PCBs individually as STEP files and imported them into FreeCAD.

I then created an assembly of both stacked PCBs to verify their relative
position and exported the complete assembly as a STEP file. I also updated
the JLCPCB cart and cleaned up temporary KiCad lock files.

Time spent: ~5 h

## July 10-15, 2026

I ordered the PCB from JLCPCB and came to some issues with a footprint of the USB CP2102 Chip.  Because I was on travel with school I replaced this part in my order on 16.07.2026.

This was my final cart for the order:
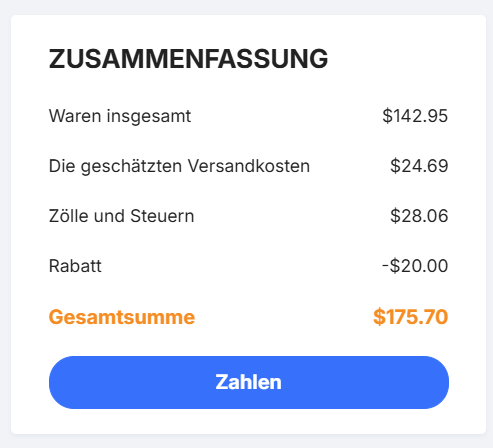
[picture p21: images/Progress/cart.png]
cart


Final BOM:
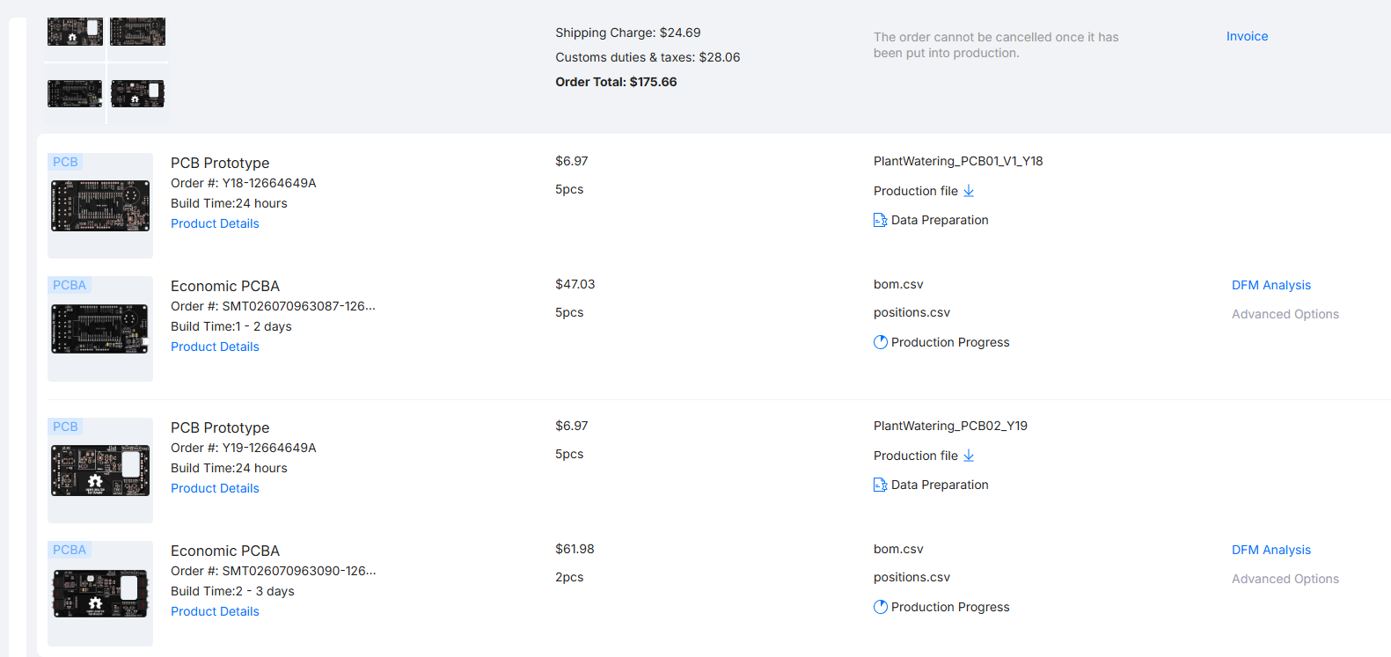
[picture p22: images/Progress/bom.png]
BOM


## July 17-23, 2026

I received an Emails about a mismatching of the audio jack. With some friendly email communication I could solve those Issues and received the boards at July 24. But I were on vacation so I could only inspect the boards when I came back at July 27.

## July 27, 2026

I unboxed the pcbs and checkt rought dimensions of the existing parts. I realised that many of the parts I would later assemble doesn't match the dimensions of the board. Therefore I had to think of some solutions for those but I was really disappointed. Eventhough I was too tired to proceed with soldering.
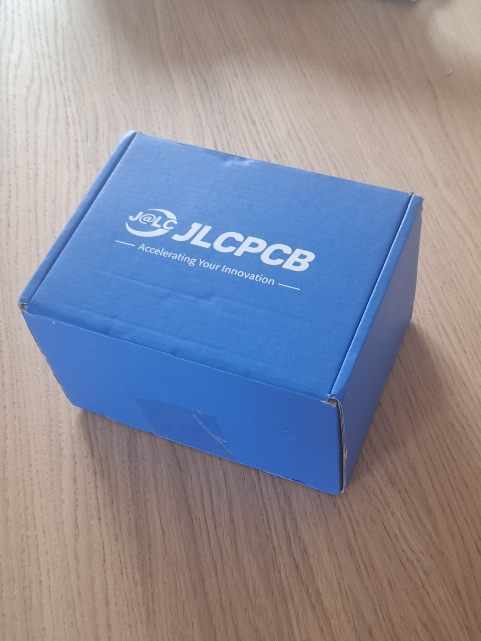
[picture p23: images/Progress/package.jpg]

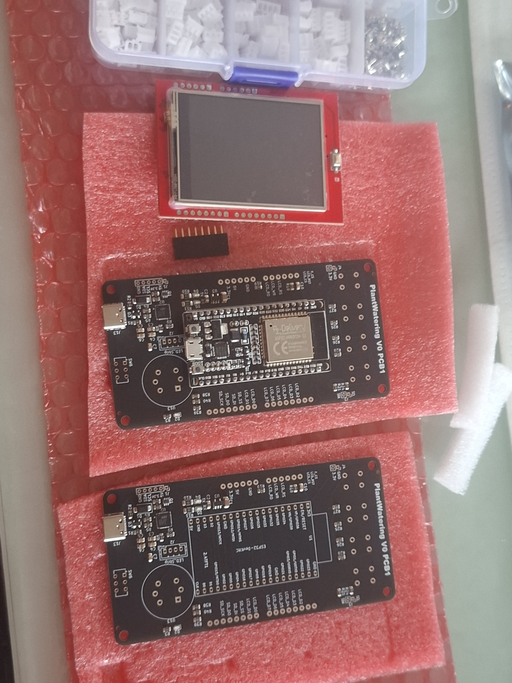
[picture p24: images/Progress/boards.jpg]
boards


## July 28, 2026

I tested the boards and as soon I as I drawed some current at some parts the cp2102 chip got hot and destroied itself. I first thought of a short circuit due to mismatching package types. Therefore I had to spend the whole day with replacing the chip and wiring the USB-c to the microusb directly.  That didn't work. I also tried to wire it to the exposed pads of the removed cp2102 but that also didn't work. I have been really disappointed.

Time spend at this day and the week before: ~8h

## July 29, 2026

I proceed with yesterdays strategie but I had to start over with a new board I realiesed that the short circuit only appered when I had soldered the MQ2 Sensor to the board. therefore I looked into the schematic again an noticed that all current has to float through the cp2102 chip. I had the solution that I wired a parallel wire to the dcdc converter of the esp32devkit c directly to split the current and prevent it of floating through only one thin wire. That suprisingly worked fantastic! Even the display turned on and every status LED lighted up as intended. Now I only have to test the data transphere...

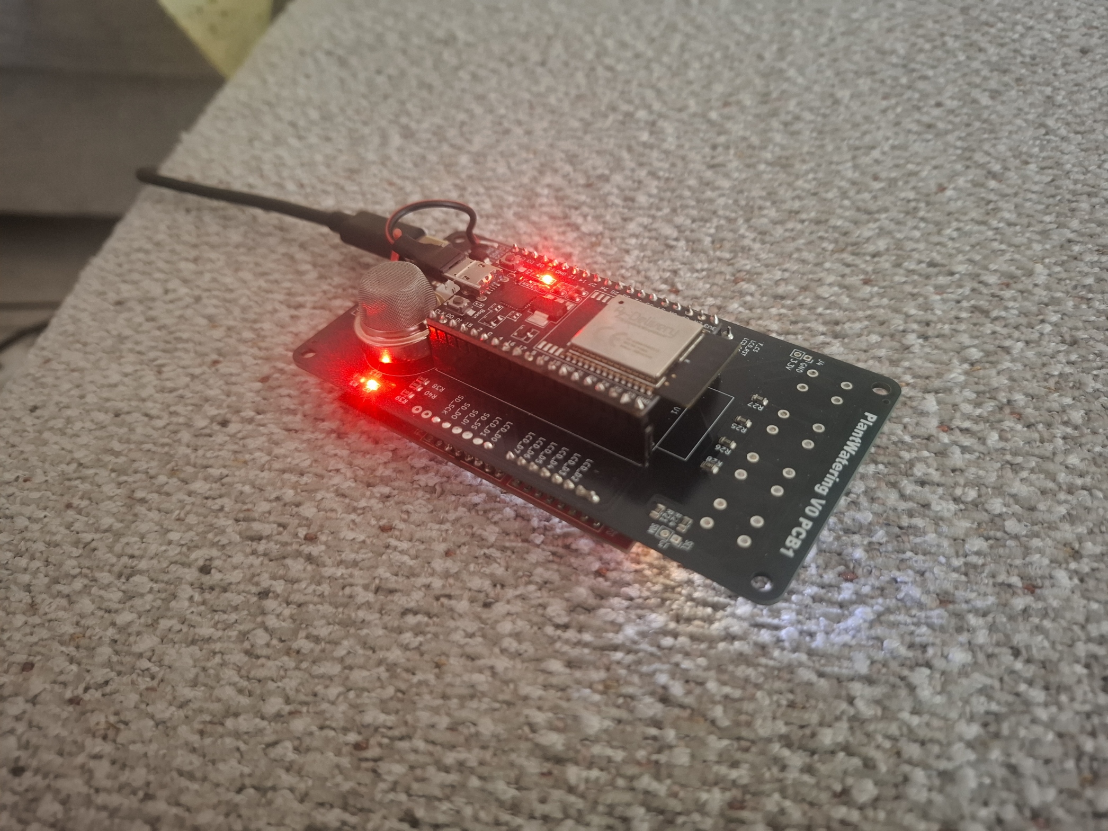
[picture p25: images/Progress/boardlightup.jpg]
board

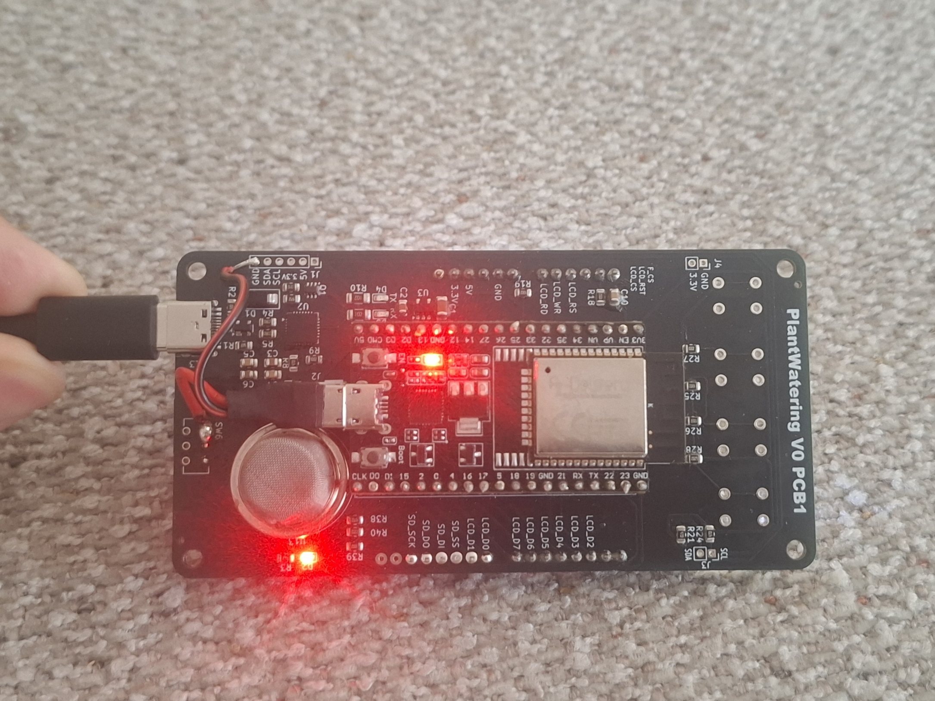
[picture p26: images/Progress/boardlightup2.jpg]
board


This struggle took very long: ~5h

edit: no success while coding. SD mount failed, USB communication doesn't work. I actually don't want to proceed. Time wasted here: at least 3h

## July 30 - 31, 2026

I fixed SD failures. I succeed by showing up the lizard video on the screen. I am not able to use the USB-C. I forgot to cross the UART cables and end up wiring those manually to the Devkit C. Eventhough the communication didn't worked. I also soldered the buttons directly to the board and tested them. They worked perfect and also the MQ2 Gas sensor worked without any bigger issues.
I also tested the battery and the boost converter they worked perfect :) Next step is to test the I2C communication and to find out if or how to find around the usb connection issues.

Time spend: 6h

## August 1 2026

I laied the hardware issues to the side and started coding. I coded a selfcheck class that automatically initializes the components of the board. I had to do some debugging but on August 2 the first part of my code all worked fine!
Time spend: 4h

## August 2 2026

I tried to use functilns of board 2 but after quite a bit of software bugs and some new functions nobody ever asked for I found out that the wire to board 2 were broken and the board wasn't even supplied by power.
I soldered new connectors to the board and reached the state of August 1. But I also did some research on GUI engines.
Time spend: ~ 2h

## August 3 2026

My goal for today was to get the LEDs working properly And to address the ADCs. But before I could start I had to realise that again some connectors didn't properly connect. So again soldering of wires that don't want to stick in the holes they're supposed to.
Finally everything was connected I asked AI to find software bugs. My self check class couldn't have worked or thrown an error because the begin functions don't throw an error but return non-zero values so I had to modify the complete class. In the end it worked so it thrower errors. But I didn't want to get those errors. It started with simple Errors that the ADCs and the clock couldn't be addressed or called by their begin functions. I tried a lot but that didn't worked. I got even more cable broken at their connectors, my Laptop was constantly throwing errors because the connected device was pulling too much power from the USB port because I probably miswired the MQ2 so it heated up to more than 60°C... Anyway I had a successful I2C scan. but as I wanted to repeat it it didn't work. I thought it would have been a software bug but it turned out to be another hardware problem.
It took me hours until I decided to turn all over. Until then I had already tried to throw away all files aren't necessary needed. 
But then I started wir a new board. I learned from my mistakes with board 1 and 2 and tried to connect everything using connectors then can easily be removed. Finally after I had soldered alle components except for the buttons and the MQ2 I could successfully use the I2C of the ESP32 Devkit c. It took me again a lot of time until I reached the state of August 1. Eventough the LEDs still don't light up and the SD card doesn't work I had wasted around 8.5 hours of my life here and still don't really know what the error was. It was one of my least successful and enjoyable days this year. I think it was the last bigger project in my life.

Time spend: 8.5h

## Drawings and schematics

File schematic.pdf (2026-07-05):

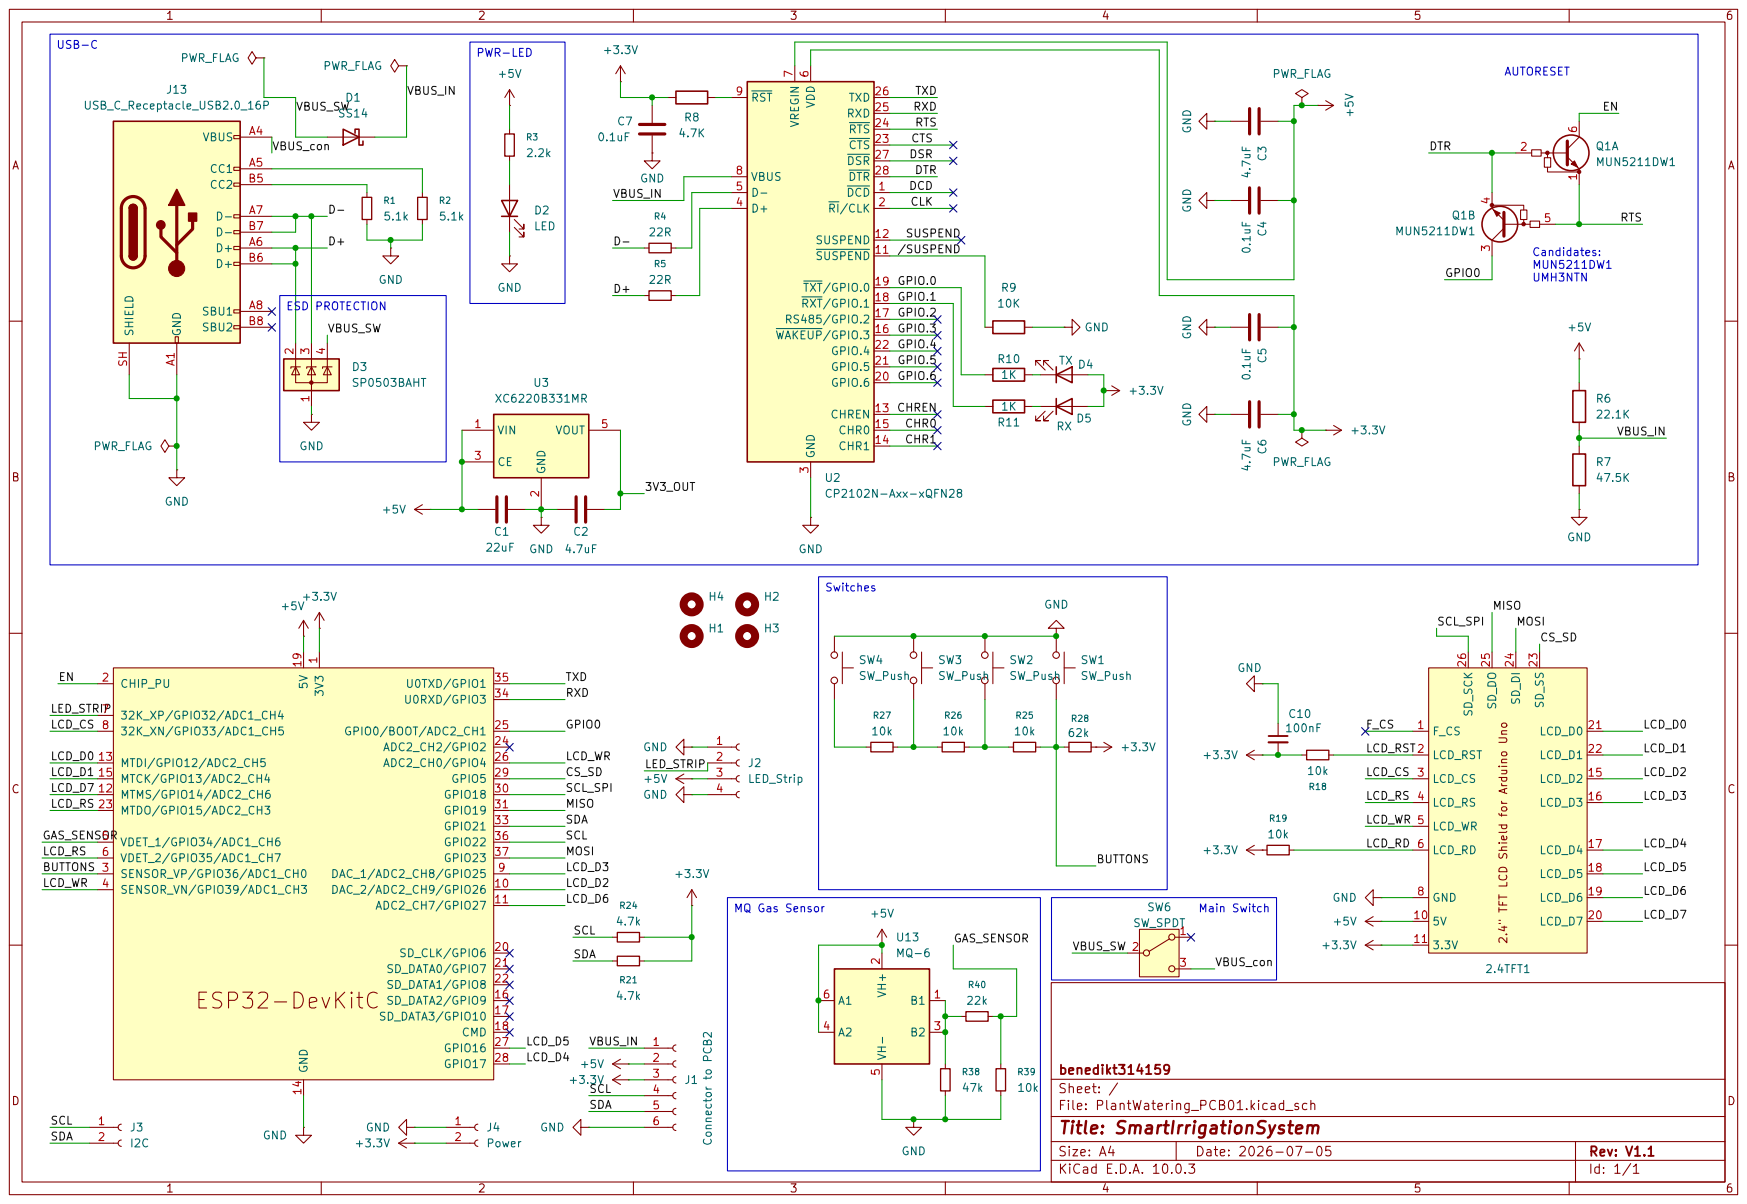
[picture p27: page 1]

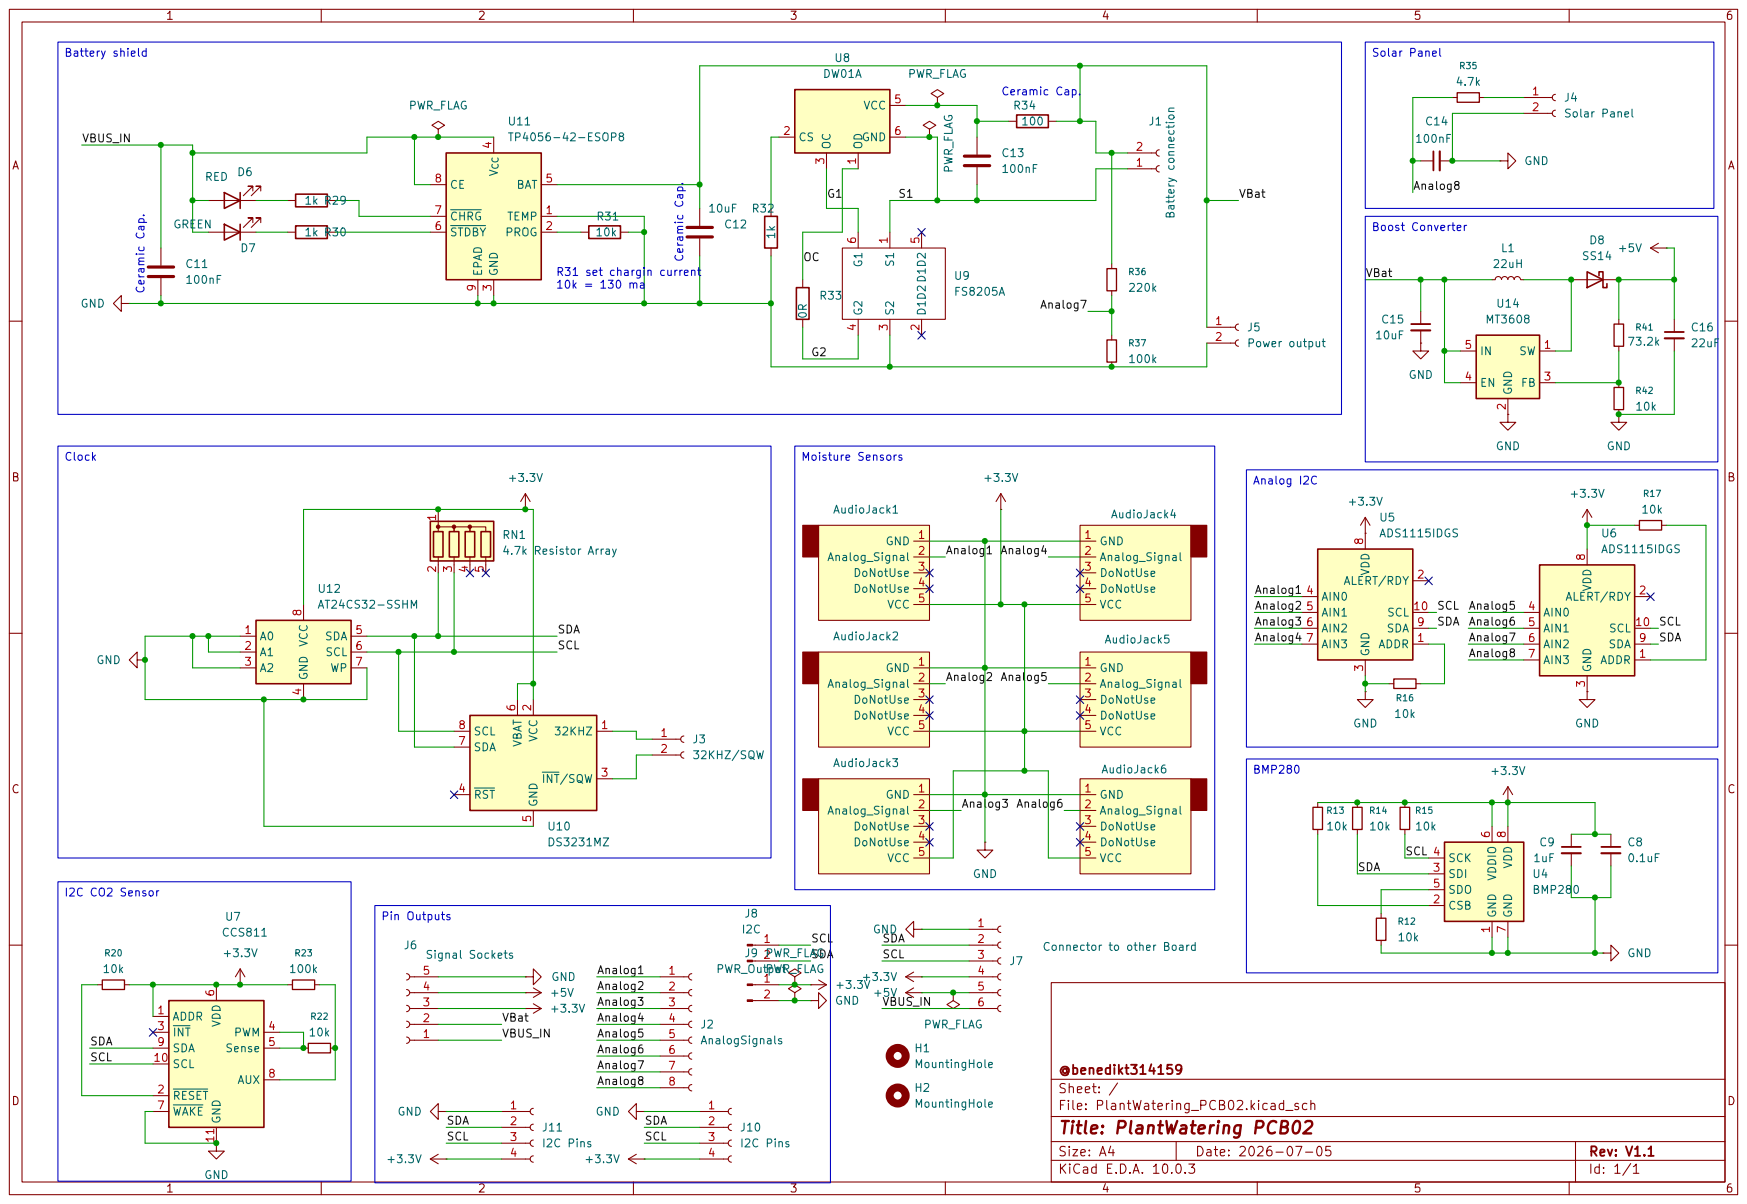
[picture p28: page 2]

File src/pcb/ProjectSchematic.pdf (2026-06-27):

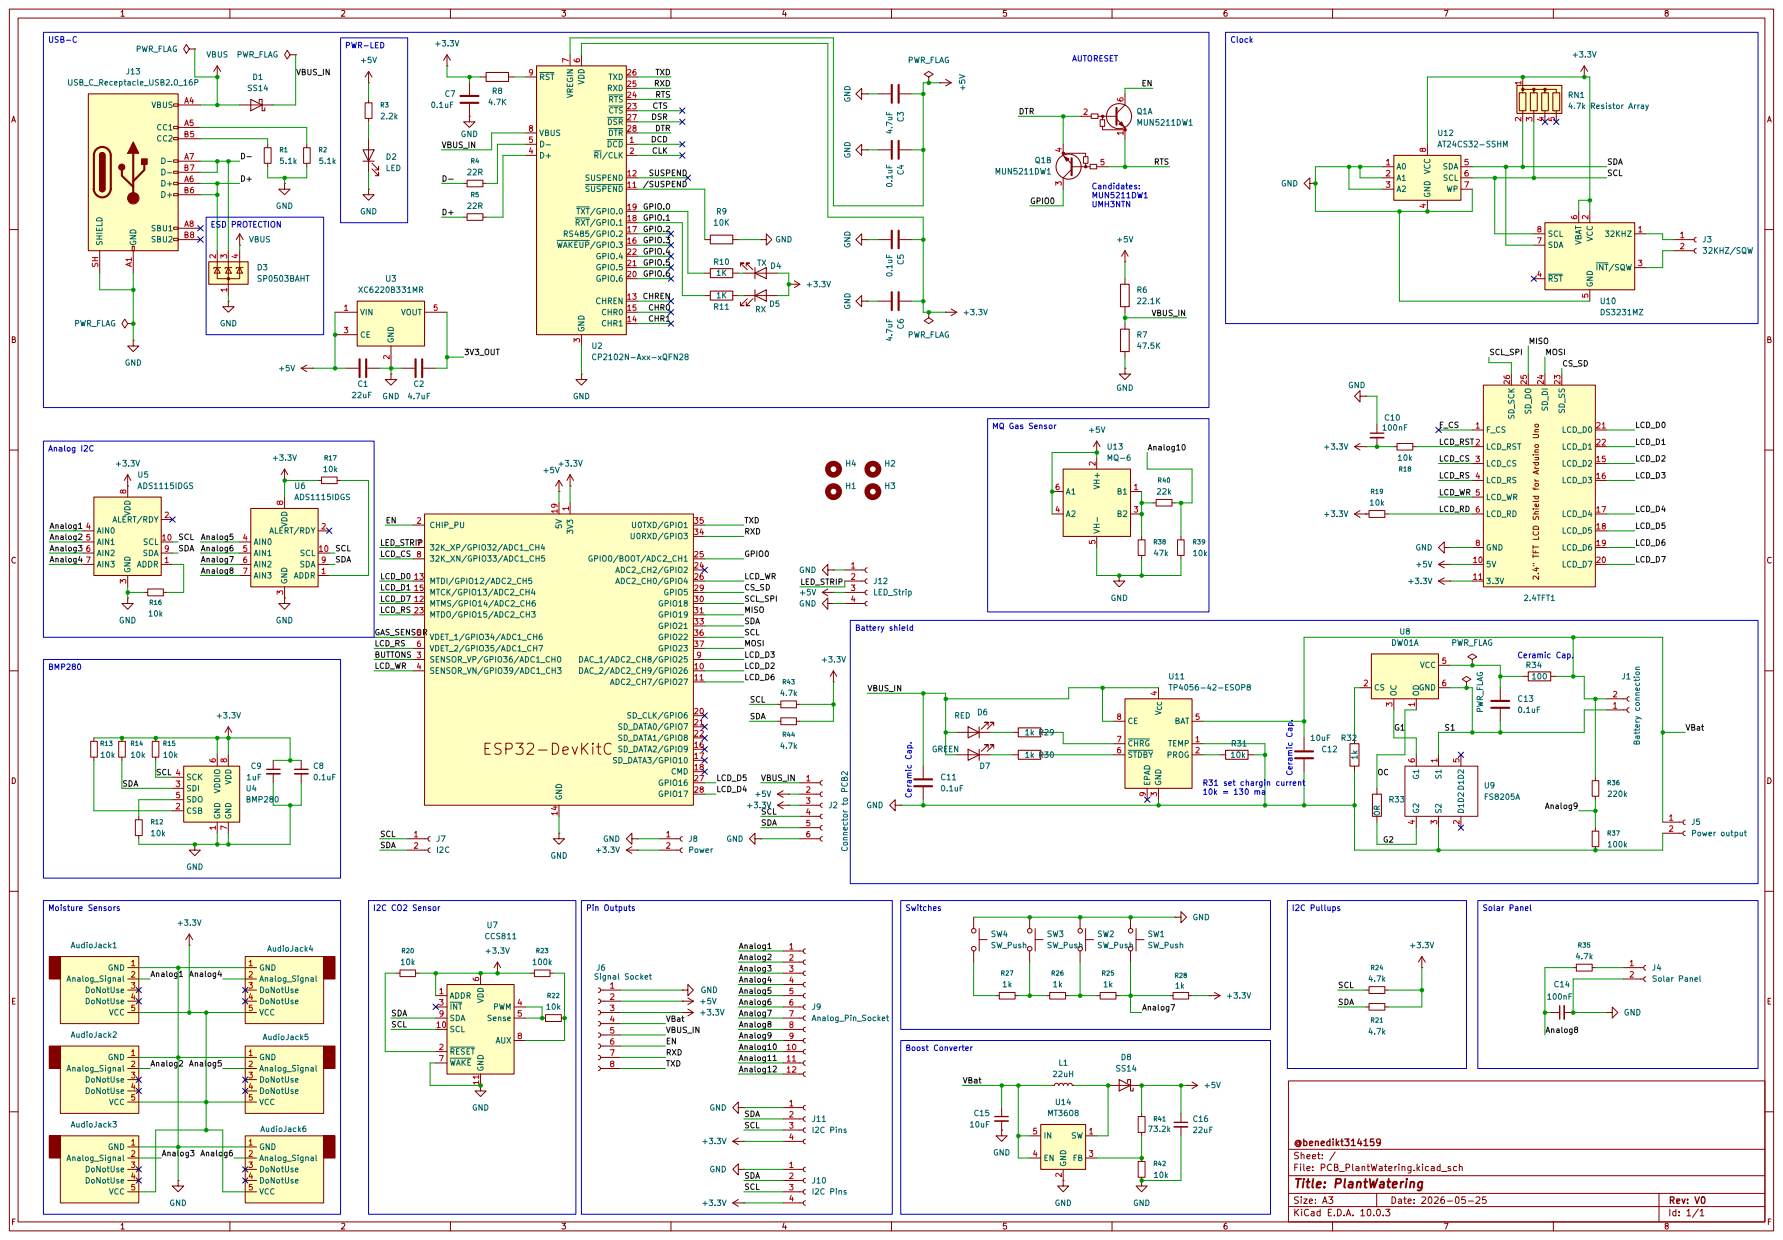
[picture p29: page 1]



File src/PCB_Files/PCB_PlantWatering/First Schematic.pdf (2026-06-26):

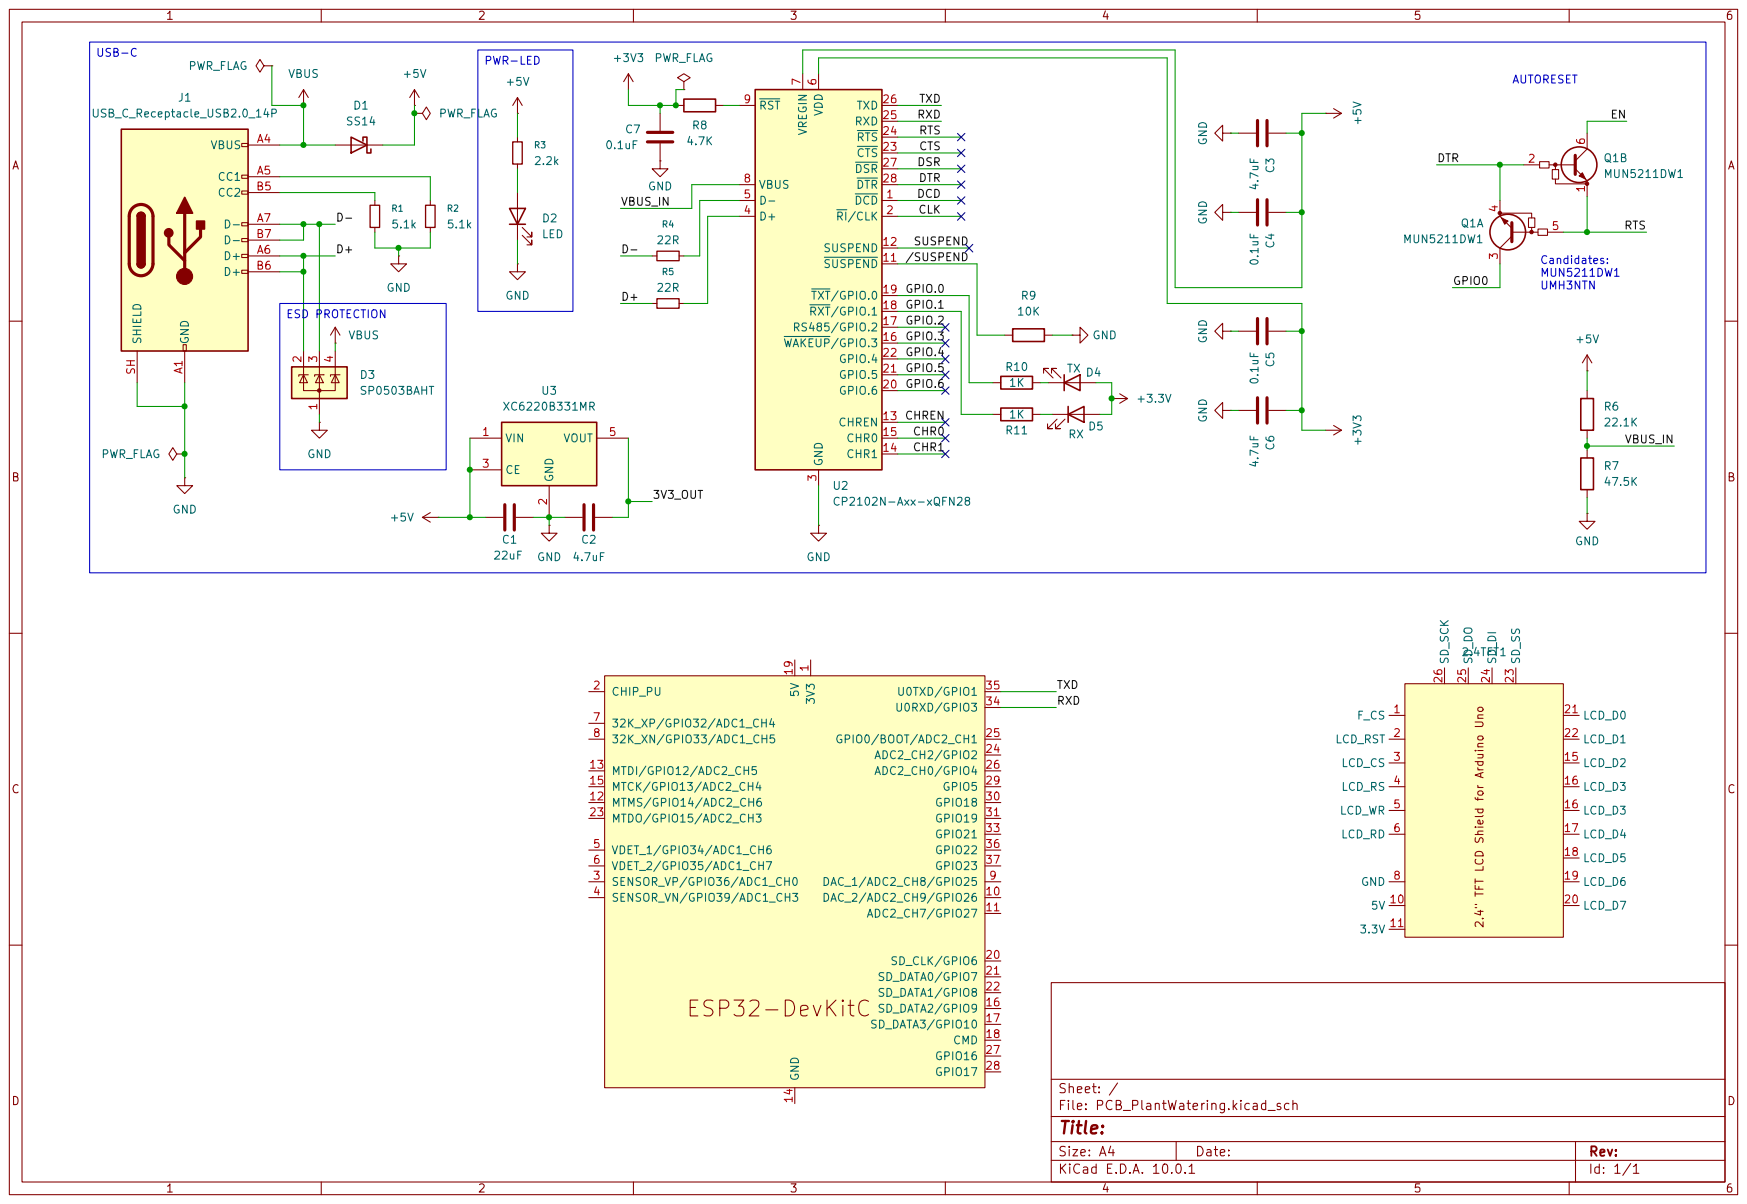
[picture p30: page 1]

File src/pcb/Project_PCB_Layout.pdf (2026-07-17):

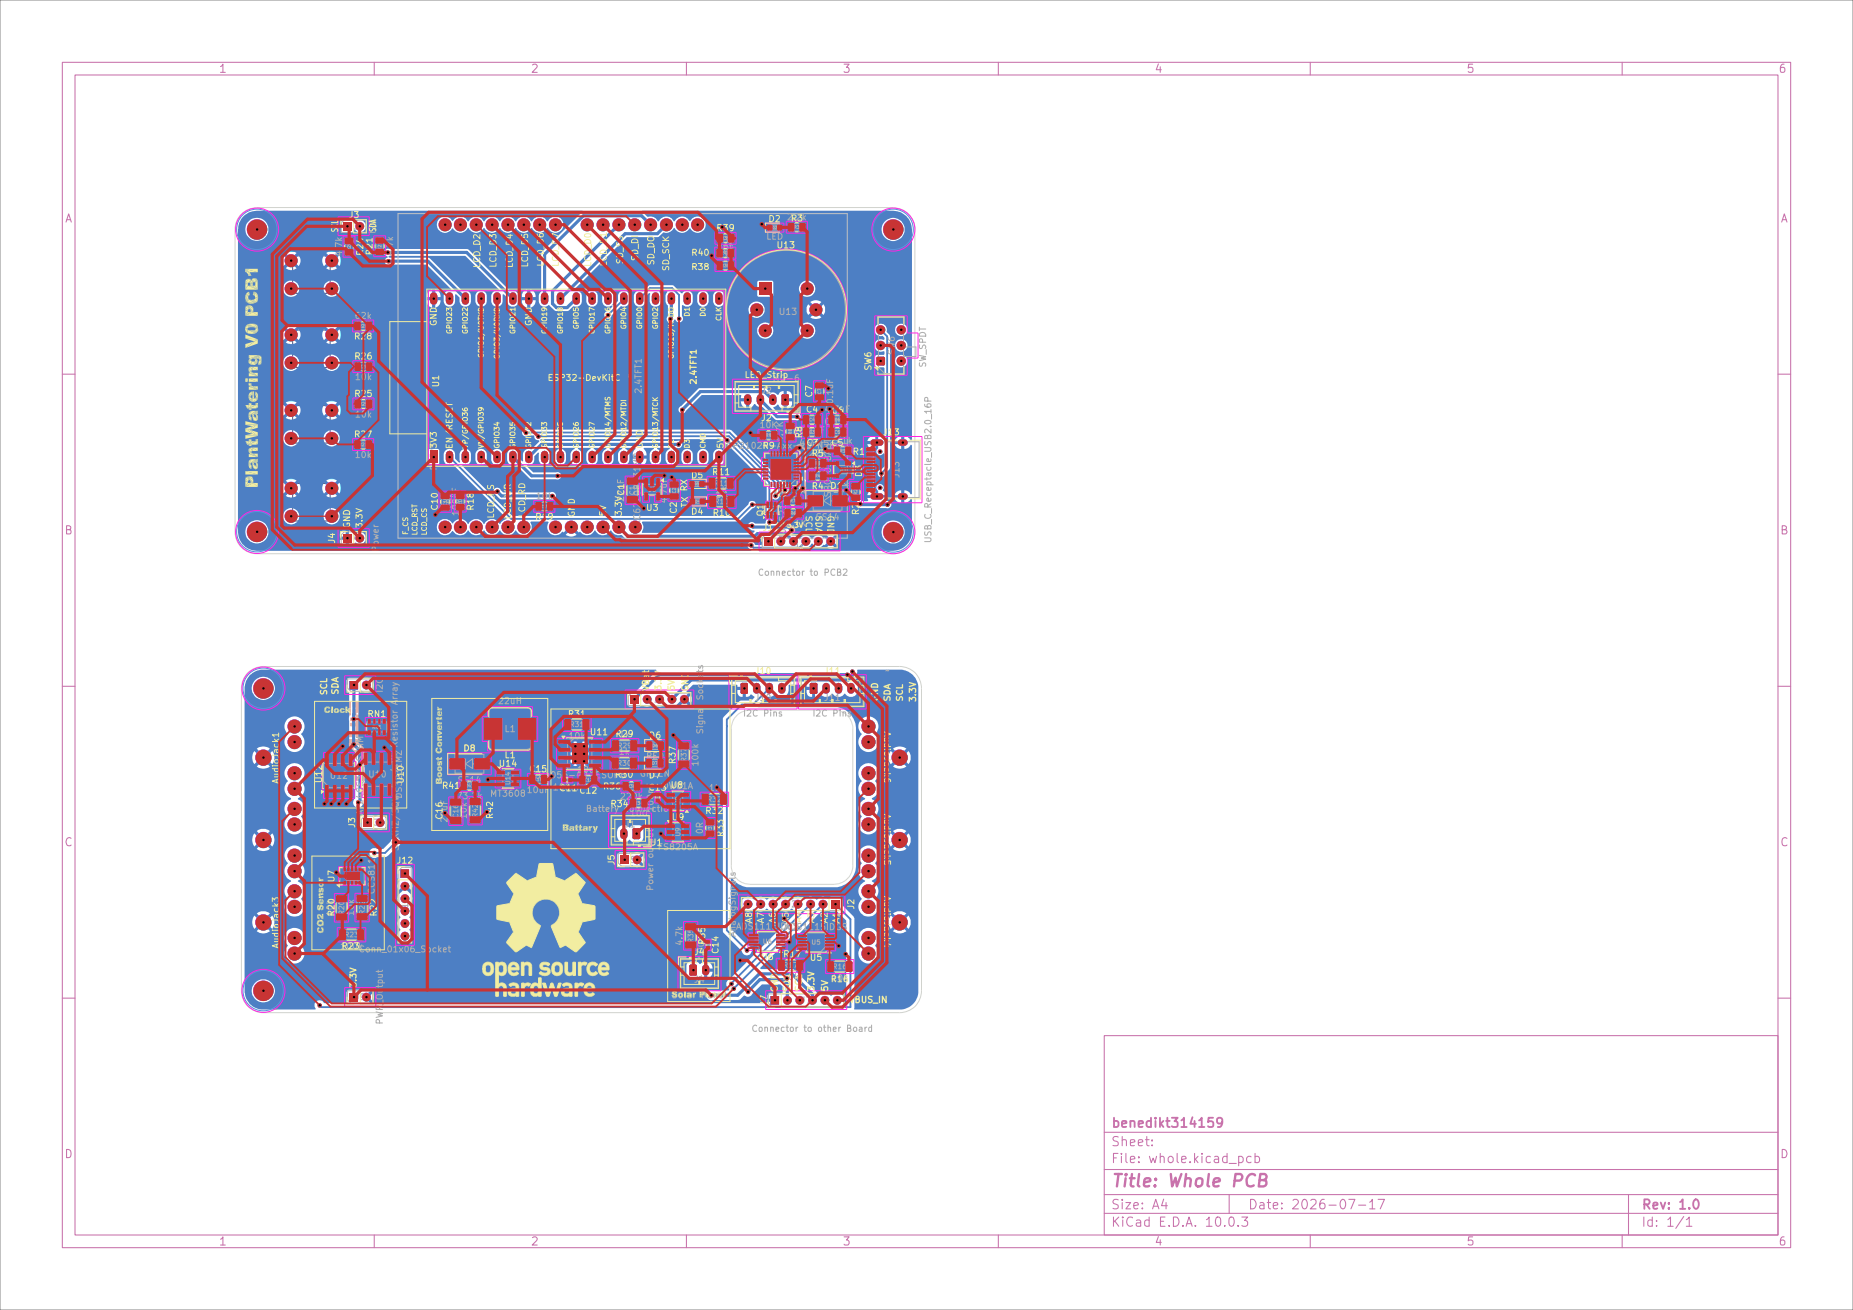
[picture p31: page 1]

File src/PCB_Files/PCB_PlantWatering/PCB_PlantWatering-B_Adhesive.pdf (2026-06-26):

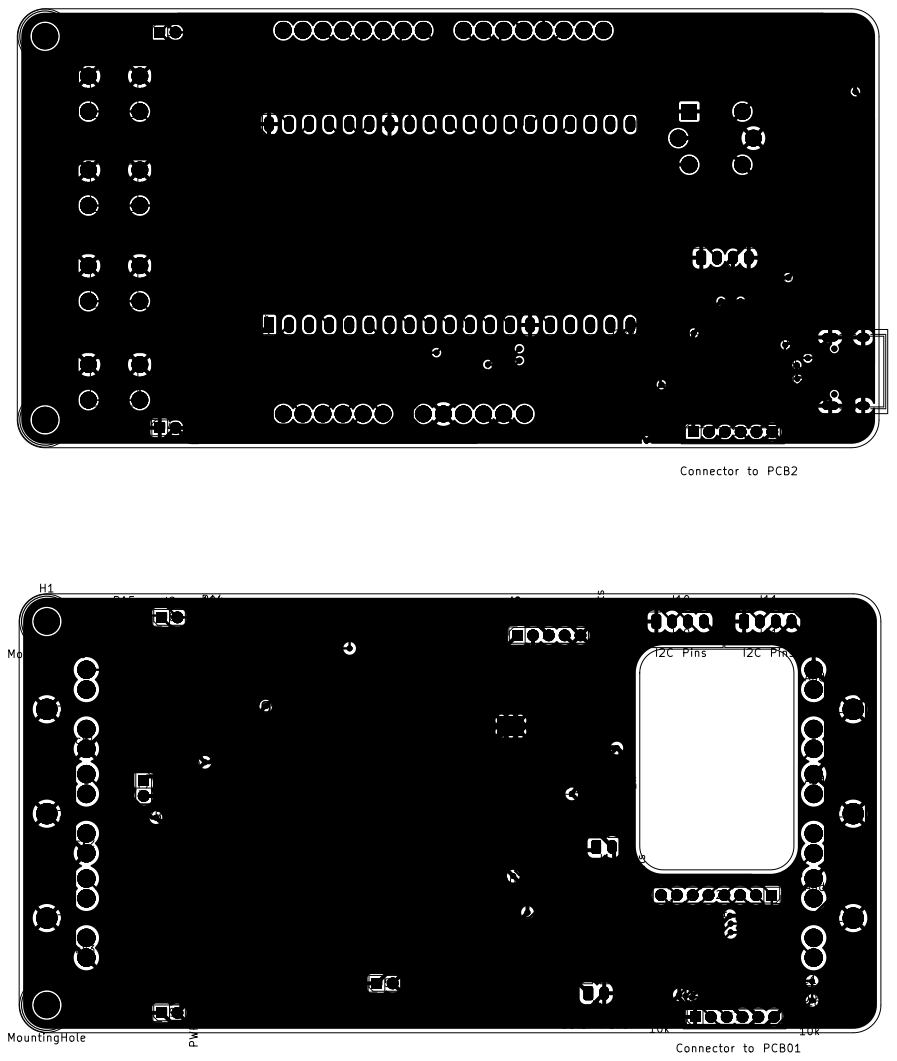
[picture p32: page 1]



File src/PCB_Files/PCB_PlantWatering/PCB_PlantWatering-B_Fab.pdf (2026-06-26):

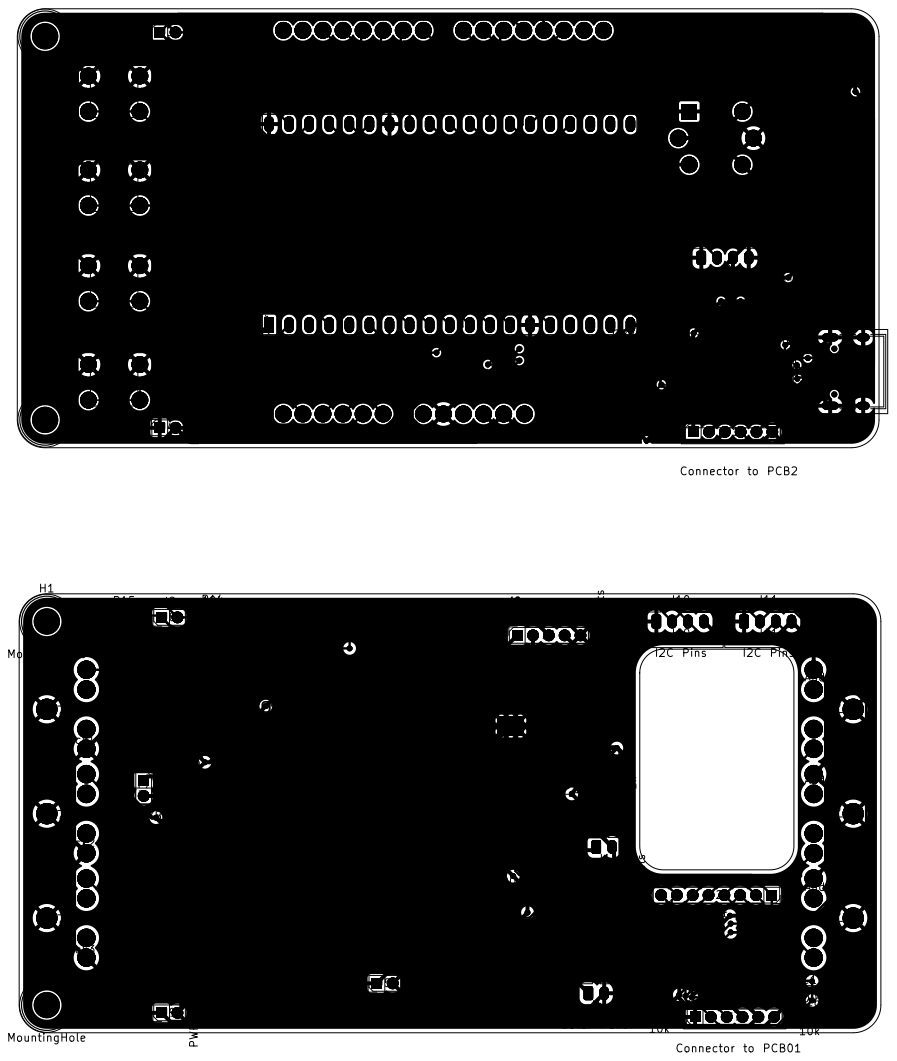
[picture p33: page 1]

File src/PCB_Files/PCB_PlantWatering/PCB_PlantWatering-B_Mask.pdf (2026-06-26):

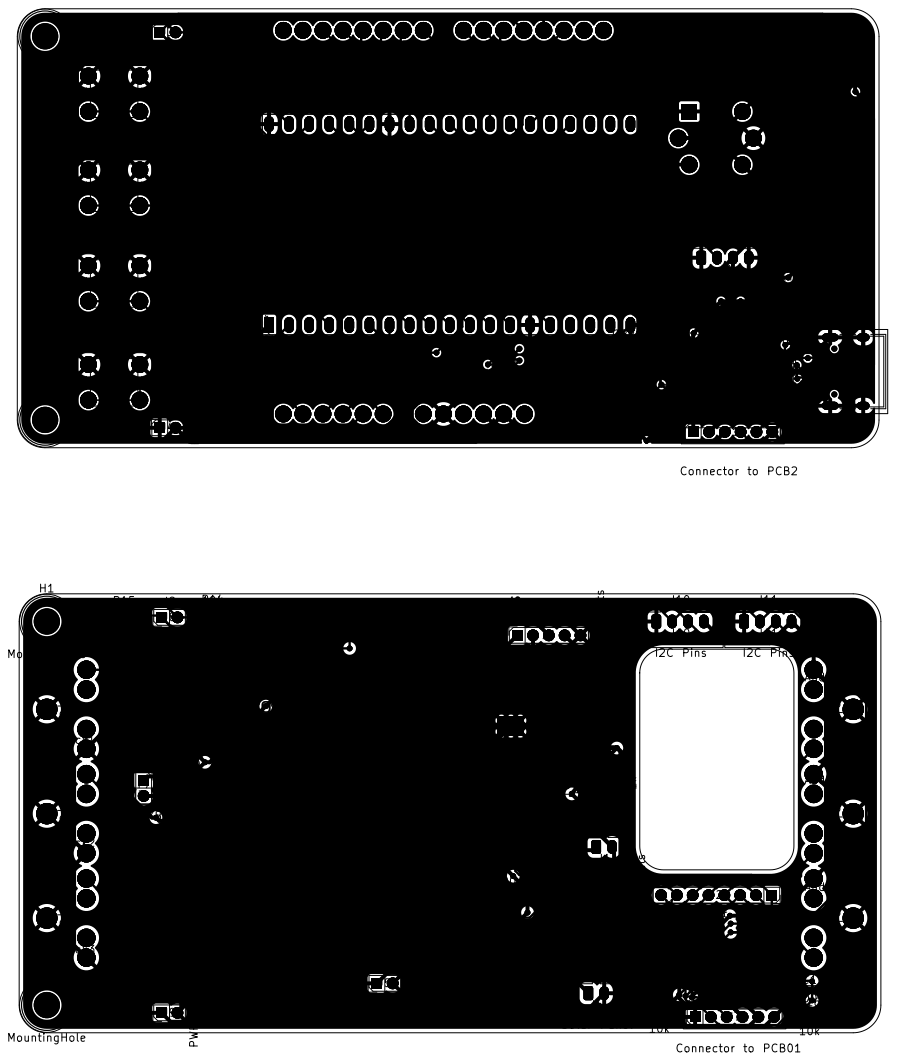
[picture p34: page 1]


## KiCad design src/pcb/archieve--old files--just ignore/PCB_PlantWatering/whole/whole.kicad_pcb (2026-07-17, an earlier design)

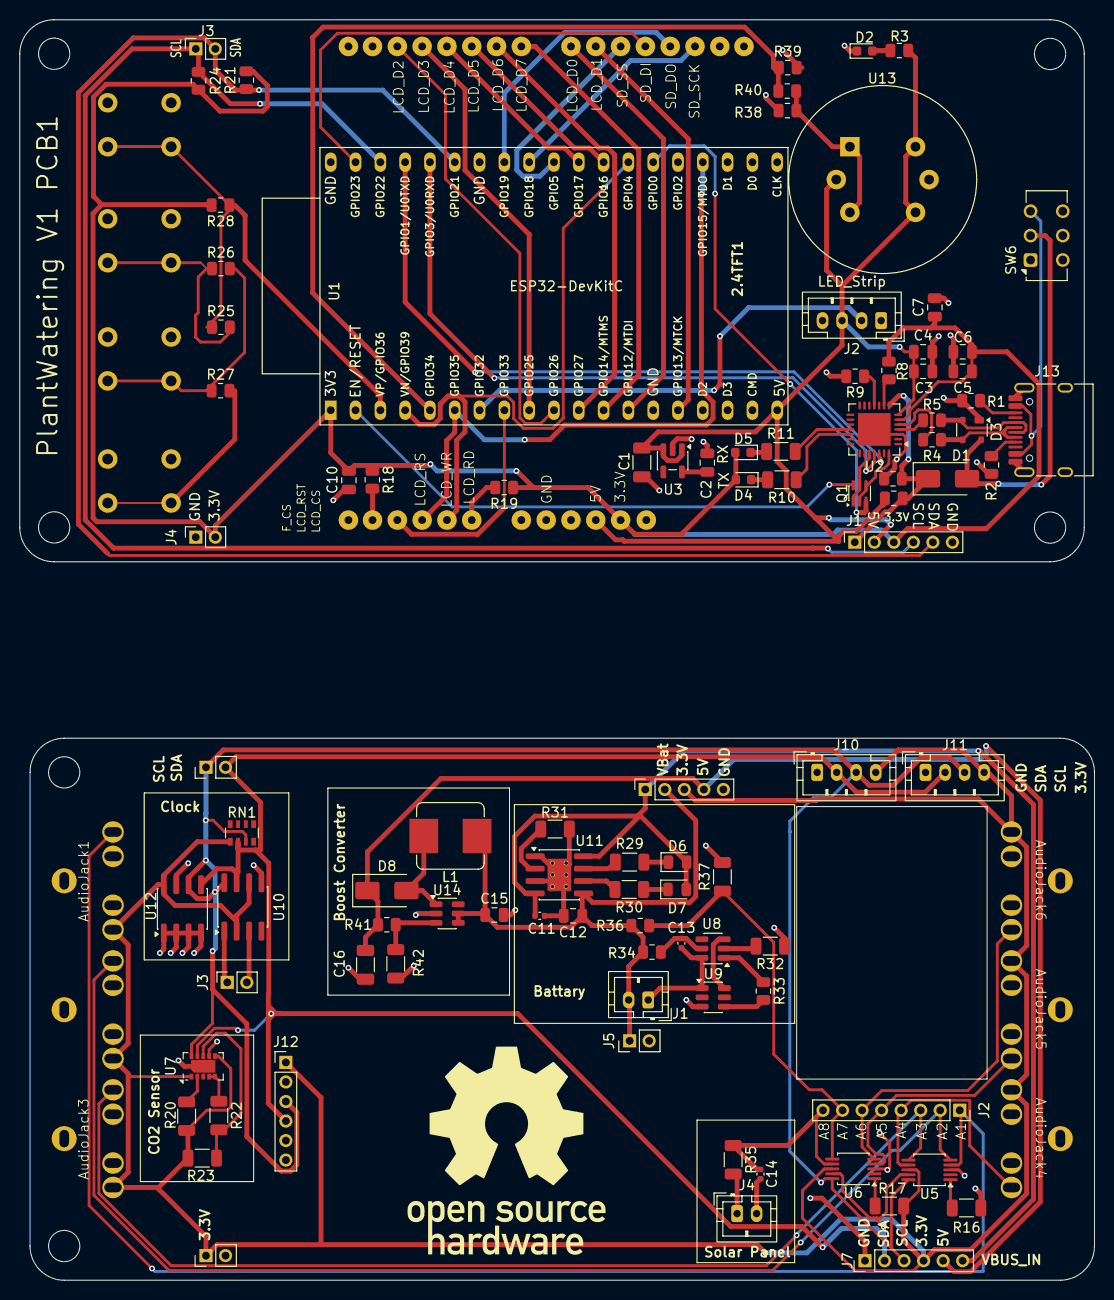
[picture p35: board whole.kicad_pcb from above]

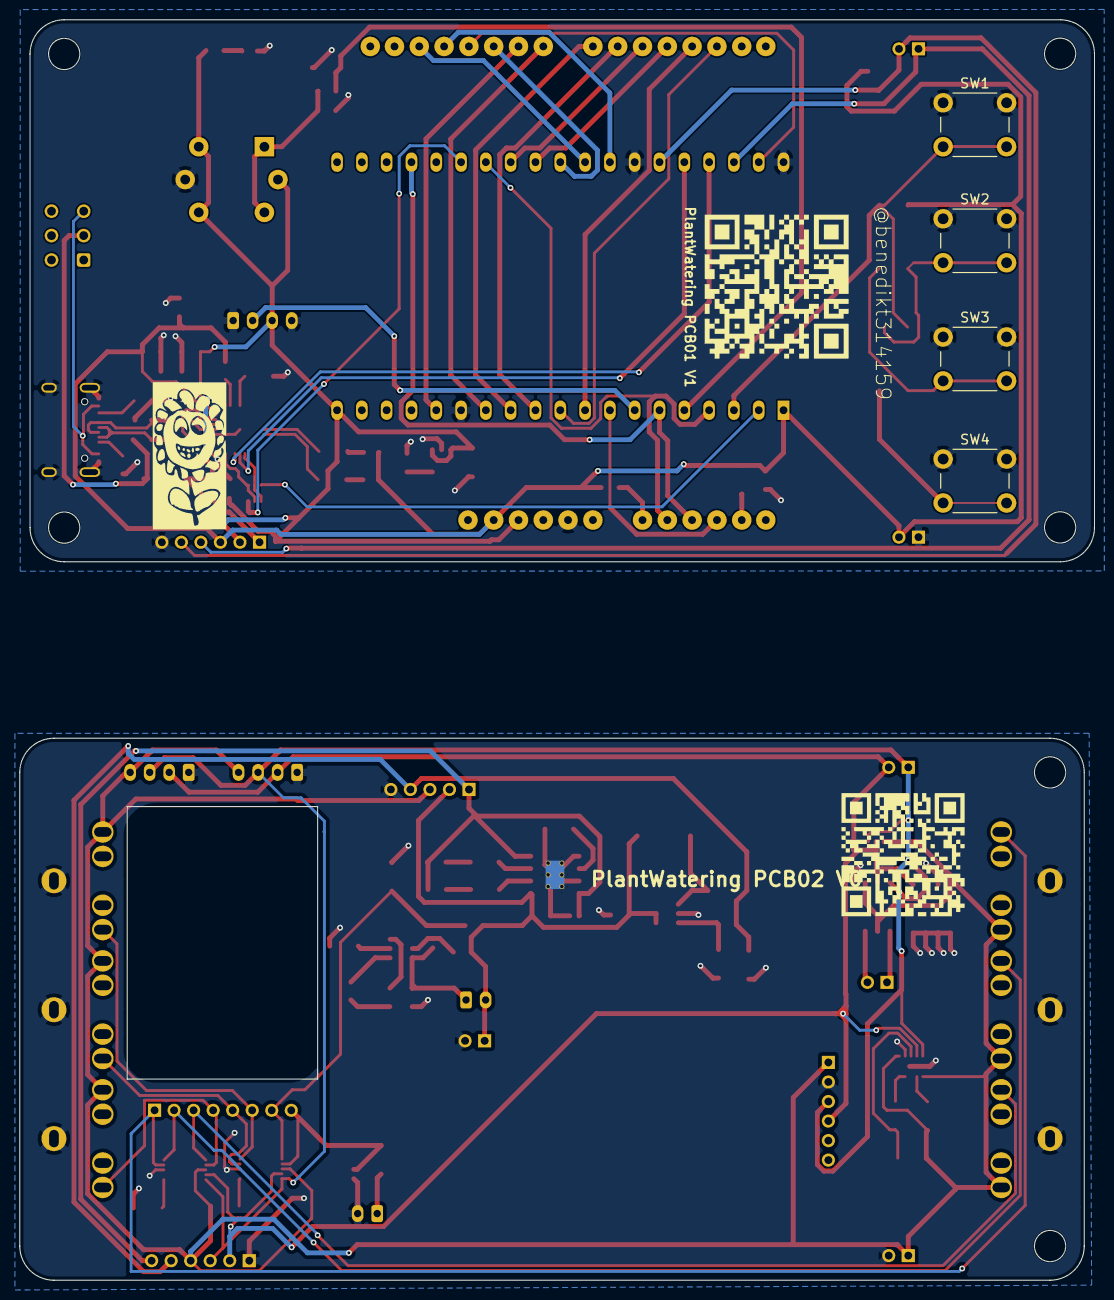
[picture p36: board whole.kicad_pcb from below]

Board: 2 copper layers, 110.0 x 129.1 mm, 111 parts (4 on the bottom side), 82 nets.

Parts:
2.4TFT1: 2.4 TFT LCD Shield
AudioJack1, AudioJack2, AudioJack3, AudioJack4, AudioJack5, AudioJack6: PJ-3126-5A
C1, C16: 22uF; C_1206_3216Metric
C2, C3, C6: 4.7uF; C_0805_2012Metric
C4, C5, C7: 0.1uF; C_0805_2012Metric
C10: 100nF; C_0805_2012Metric
C11, C13, C14: 100nF; C_0402_1005Metric
C12, C15: 10uF; C_0805_2012Metric
D1, D8: SS14; D_SMA
D2: LED; LED_0603_1608Metric
D3: SP0503BAHT; SOT-143
D4: TX; LED_0603_1608Metric
D5: RX; LED_0603_1608Metric
D6: RED; LED_0805_2012Metric
D7: GREEN; LED_0805_2012Metric
H1, H1#2, H2, H2#2, H3, H4: MountingHole; MountingHole_3.2mm_M3
J1: Battery connection; JST_PH_B2B-PH-K_1x02_P2.00mm_Vertical
J1#2: Connector to PCB2; PinSocket_1x06_P2.00mm_Vertical
J2: LED_Strip; JST_PH_B4B-PH-K_1x04_P2.00mm_Vertical
J2#2: AnalogSignals; PinSocket_1x08_P2.00mm_Vertical
J3: I2C; PinSocket_1x02_P2.00mm_Vertical
J3#2: 32KHZ/SQW; PinSocket_1x02_P2.00mm_Vertical
J4: Power; PinSocket_1x02_P2.00mm_Vertical
J4#2: Solar Panel; JST_PH_B2B-PH-K_1x02_P2.00mm_Vertical
J5: Power output; PinHeader_1x02_P2.00mm_Vertical
J6: Signal Sockets; PinSocket_1x05_P2.00mm_Vertical
J7: Connector to other Board; PinHeader_1x06_P2.00mm_Vertical
J8: I2C; PinHeader_1x02_P2.00mm_Vertical
J9: PWR_Output; PinHeader_1x02_P2.00mm_Vertical
J10, J11: I2C Pins; JST_PH_B4B-PH-K_1x04_P2.00mm_Vertical
J12: Conn_01x06_Socket; PinHeader_1x06_P2.00mm_Vertical
J13: USB_C_Receptacle_USB2.0_16P; USB_C_Receptacle_HRO_TYPE-C-31-M-12
L1: 22uH; L_Bourns_SRP7028A_7.3x6.6mm
Q1: MUN5211DW1; SOT-363_SC-70-6
R1, R2: 5.1k; R_0805_2012Metric
R3: 2.2k; R_0805_2012Metric
R4, R5: 22R; R_0805_2012Metric
R6: 22.1K; R_0805_2012Metric
R7: 47.5K; R_0805_2012Metric
R8: 4.7K; R_0805_2012Metric
R9: 10K; R_0805_2012Metric
R10, R11: 1K; R_1206_3216Metric
R16, R17, R20, R22, R31, R42: 10k; R_1206_3216Metric
R18, R19, R25, R26, R27, R39: 10k; R_0805_2012Metric
R21, R24: 4.7k; R_0805_2012Metric
R23, R37: 100k; R_1206_3216Metric
R28: 62k; R_0805_2012Metric
R29, R30, R32: 1k; R_1206_3216Metric
R33: 0R; R_0805_2012Metric
R34: 100; R_0805_2012Metric
R35: 4.7k; R_1206_3216Metric
R36: 220k; R_0805_2012Metric
R38: 47k; R_0805_2012Metric
R40: 22k; R_0805_2012Metric
R41: 73.2k; R_0805_2012Metric
RN1: 4.7k Resistor Array; R_Array_Convex_4x0603
SW1, SW2, SW3, SW4: SW_Push; SW_PUSH_6mm
SW6: SW_SPDT; SW_CK_JS202011AQN_DPDT_Angled
U1: ESP32-DevKitC
U2: CP2102N-Axx-xQFN28; QFN-28-1EP_5x5mm_P0.5mm_EP3.35x3.35mm
U3: XC6220B331MR; SOT-23-5
U5, U6: ADS1115IDGS; TSSOP-10_3x3mm_P0.5mm
U7: CCS811; AMS_LGA-10-1EP_2.7x4mm_P0.6mm
U8: DW01A; SOT-23-6
U9: FS8205A; SOT-23-6
U10: DS3231MZ; SOIC-8_3.9x4.9mm_P1.27mm
U11: TP4056-42-ESOP8; SOIC-8-1EP_3.9x4.9mm_P1.27mm_EP2.41x3.3mm_ThermalVias
U12: AT24CS32-SSHM; SOIC-8_3.9x4.9mm_P1.27mm
U13: MQ-6
U14: MT3608; SOT-23-6

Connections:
+3.3V: 2.4TFT1.11 (3.3V), AudioJack1.5 (VCC), AudioJack2.5 (VCC), AudioJack3.5 (VCC), AudioJack4.5 (VCC), AudioJack5.5 (VCC), AudioJack6.5 (VCC), C5.1, C6.1, C7.1, C10.2, D4.2 (A), D5.2 (A), J1#2.3, J4.2, J6.3, J7.4, J9.1, J10.4, J11.4, J12.1, R8.1, R17.2, R18.1, R19.1, R20.2, R21.2, R23.1, R24.2, R28.2, RN1.1 (common), U1.1 (3V3), U2.6 (VDD), U5.8 (VDD), U6.8 (VDD), U7.1 (ADDR), U7.6 (VDD), U10.2 (VCC), U10.6 (VBAT), U12.8 (VCC)
+5V: 2.4TFT1.10 (5V), C1.1, C3.1, C4.1, C16.1, D8.1 (K), J1#2.2, J2.3, J6.4, J7.5, R3.1, R6.1, R41.1, U1.19 (5V), U2.7 (VREGIN), U3.1 (VIN), U3.3 (CE), U13.2 (VH+), U13.4 (A2), U13.6 (A1)
/3V3_OUT: C2.2, U3.5 (VOUT)
/Analog1: AudioJack1.2 (Analog_Signal), J2#2.1, U5.4 (AIN0)
/Analog2: AudioJack2.2 (Analog_Signal), J2#2.2, U5.5 (AIN1)
/Analog3: AudioJack3.2 (Analog_Signal), J2#2.3, U5.6 (AIN2)
/Analog4: AudioJack4.2 (Analog_Signal), J2#2.4, U5.7 (AIN3)
/Analog5: AudioJack5.2 (Analog_Signal), J2#2.5, U6.4 (AIN0)
/Analog6: AudioJack6.2 (Analog_Signal), J2#2.6, U6.5 (AIN1)
/Analog7: J2#2.7, R36.2, R37.1, U6.6 (AIN2)
/Analog8: C14.1, J2#2.8, R35.1, U6.7 (AIN3)
/BUTTONS: R25.1, R28.1, SW1.2, U1.3 (SENSOR_VP/GPIO36/ADC1_CH0)
/CS_SD: 2.4TFT1.23 (SD_SS), U1.29 (GPIO5)
/D+: D3.2 (K), J13.A6 (D+), J13.B6 (D+), R5.1
/D-: D3.3 (K), J13.A7 (D-), J13.B7 (D-), R4.1
/DTR: Q1.2 (B1), Q1.4 (E2), U2.28 (~DTR)
/EN: Q1.6 (C1), U1.2 (CHIP_PU)
/G1: U8.3 (OC), U9.6 (G1)
/G2: R33.2, U9.4 (G2)
/GAS_SENSOR: R39.1, R40.2, U1.5 (VDET_1/GPIO34/ADC1_CH6)
/GPIO0: Q1.3 (C2), U1.25 (GPIO0/BOOT/ADC2_CH1)
/GPIO.0: R10.1, U2.19 (~TXT/GPIO.0)
/GPIO.1: R11.2, U2.18 (~RXT/GPIO.1)
/LCD_CS: 2.4TFT1.3 (LCD_CS), U1.8 (32K_XN/GPIO33/ADC1_CH5)
/LCD_D0: 2.4TFT1.21 (LCD_D0), U1.13 (MTDI/GPIO12/ADC2_CH5)
/LCD_D1: 2.4TFT1.22 (LCD_D1), U1.15 (MTCK/GPIO13/ADC2_CH4)
/LCD_D2: 2.4TFT1.15 (LCD_D2), U1.10 (DAC_2/ADC2_CH9/GPIO26)
/LCD_D3: 2.4TFT1.16 (LCD_D3), U1.9 (DAC_1/ADC2_CH8/GPIO25)
/LCD_D4: 2.4TFT1.17 (LCD_D4), U1.28 (GPIO17)
/LCD_D5: 2.4TFT1.18 (LCD_D5), U1.27 (GPIO16)
/LCD_D6: 2.4TFT1.19 (LCD_D6), U1.11 (ADC2_CH7/GPIO27)
/LCD_D7: 2.4TFT1.20 (LCD_D7), U1.12 (MTMS/GPIO14/ADC2_CH6)
/LCD_RD: 2.4TFT1.6 (LCD_RD), R19.2
/LCD_RS: 2.4TFT1.4 (LCD_RS), U1.6 (VDET_2/GPIO35/ADC1_CH7), U1.23 (MTDO/GPIO15/ADC2_CH3)
/LCD_RST: 2.4TFT1.2 (LCD_RST), R18.2
/LCD_WR: 2.4TFT1.5 (LCD_WR), U1.4 (SENSOR_VN/GPIO39/ADC1_CH3), U1.26 (ADC2_CH0/GPIO4)
/LED_STRIP: J2.2, U1.7 (32K_XP/GPIO32/ADC1_CH4)
/MISO: 2.4TFT1.25 (SD_DO), U1.31 (GPIO19)
/MOSI: 2.4TFT1.24 (SD_DI), U1.37 (GPIO23)
/OC: R33.1, U8.1 (OD)
/RTS: Q1.1 (E1), Q1.5 (B2), U2.24 (~RTS)
/RXD: U1.34 (U0RXD/GPIO3), U2.25 (RXD)
/S1: C13.2, J1.1, U8.6 (GND), U9.1 (S1)
/SCL: J1#2.4, J3.1, J7.3, J8.1, J10.3, J11.3, J12.3, R24.1, RN1.3 (R2), U1.36 (GPIO22), U5.10 (SCL), U6.10 (SCL), U7.10 (SCL), U10.8 (SCL), U12.6 (SCL)
/SCL_SPI: 2.4TFT1.26 (SD_SCK), U1.30 (GPIO18)
/SDA: J1#2.5, J3.2, J7.2, J8.2, J10.2, J11.2, J12.4, R21.1, RN1.2 (R1), U1.33 (GPIO21), U5.9 (SDA), U6.9 (SDA), U7.9 (SDA), U10.7 (SDA), U12.5 (SDA)
/TXD: U1.35 (U0TXD/GPIO1), U2.26 (TXD)
/VBUS_IN: C11.1, D1.1 (K), D6.2 (A), D7.2 (A), J1#2.1, J6.1, J7.6, R6.2, R7.1, U2.8 (VBUS), U11.4 (V_{CC}), U11.8 (CE)
/VBUS_SW: D1.2 (A), D3.4 (K), SW6.2 (B)
/VBUS_con: J13.A4 (VBUS), J13.A9 (VBUS), J13.B4 (VBUS), J13.B9 (VBUS), SW6.3 (C)
/VBat: C12.1, C15.1, J1.2, J5.1, J6.2, L1.1, R34.1, R36.1, U11.5 (BAT), U14.4 (EN), U14.5 (IN)
//SUSPEND: R9.1, U2.11 (~SUSPEND)
GND: 2.4TFT1.8 (GND), AudioJack1.1 (GND), AudioJack2.1 (GND), AudioJack3.1 (GND), AudioJack4.1 (GND), AudioJack5.1 (GND), AudioJack6.1 (GND), C1.2, C2.1, C3.2, C4.2, C5.2, C6.2, C7.2, C10.1, C11.2, C12.2, C14.2, C15.2, C16.2, D2.1 (K), D3.1 (A), J1#2.6, J2.1, J2.4, J4.1, J4#2.2, J5.2, J6.5, J7.1, J9.2, J10.1, J11.1, J12.2, J13.A1 (GND), J13.A12 (GND), J13.B1 (GND), J13.B12 (GND), J13.SH (SHIELD), R1.2, R2.2, R7.2, R9.2, R16.2, R31.2, R32.1, R37.2, R38.2, R39.2, R42.2, SW1.1, SW2.1, SW3.1, SW4.1, U1.14 (GND), U1.32 (GND), U1.38 (GND), U2.3 (GND), U2.29 (GND), U3.2 (GND), U5.3 (GND), U6.3 (GND), U7.7 (~WAKE), U7.11 (GND), U9.3 (S2), U10.5 (GND), U11.1 (TEMP), U11.3 (GND), U11.9 (EPAD), U12.1 (A0), U12.2 (A1), U12.3 (A2), U12.4 (GND), U12.7 (WP), U13.5 (VH-), U14.2 (GND)
unnamed: D2.2 (A), R3.2
unnamed: D4.1 (K), R10.2
unnamed: D5.1 (K), R11.1
unnamed: D6.1 (K), R29.1
unnamed: D7.1 (K), R30.1
unnamed: D8.2 (A), L1.2, U14.1 (SW)
unnamed: J3#2.1, U10.1 (32KHZ)
unnamed: J3#2.2, U10.3 (~INT/SQW)
unnamed: J4#2.1, R35.2
unnamed: J13.A5 (CC1), R2.1
unnamed: J13.B5 (CC2), R1.1
unnamed: R25.2, R26.1, SW2.2
unnamed: R26.2, R27.1, SW3.2
unnamed: R27.2, SW4.2
unnamed: R5.2, U2.4 (D+)
unnamed: R4.2, U2.5 (D-)
unnamed: R8.2, U2.9 (~RST)
unnamed: R16.1, U5.1 (ADDR)
unnamed: R17.1, U6.1 (ADDR)
unnamed: R22.2, R23.2, U7.8 (AUX)
unnamed: R22.1, U7.4 (PWM), U7.5 (Sense)
unnamed: R20.1, U7.2 (~RESET)
unnamed: R32.2, U8.2 (CS)
unnamed: C13.1, R34.2, U8.5 (VCC)
unnamed: R31.1, U11.2 (PROG)
unnamed: R29.2, U11.7 (~CHRG)
unnamed: R30.2, U11.6 (~STDBY)
unnamed: R38.1, R40.1, U13.1 (B1), U13.3 (B2)
unnamed: R41.2, R42.1, U14.3 (FB)

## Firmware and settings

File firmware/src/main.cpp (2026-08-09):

#define ESP32_WIFI_TOUCH

// General
#include <Arduino.h>
#include <Wire.h>
// Repository specific headers
#include "pindefinitions.h"
#include "functions.h"
#include "Buttons.h" //the button code that would mess up the main code
#include "Touch_PCB01.h"
// SD-Card
#include <SPI.h>
#include <SD.h>
#include "FS.h"
// Display
#include <TFT_eSPI.h>
#include <TouchScreen.h>
#include <JPEGDEC.h>
#include <lvgl.h>
//Sensors
#include <RTClib.h>
#include <Adafruit_BMP280.h>
#include "MQ2.h" // library: https://github.com/labay11/MQ-2-sensor-library <- Thank you so much!
#include <Adafruit_ADS1X15.h>
//LEDs
#include <Adafruit_NeoPixel.h>


Adafruit_BMP280 bmp; // use I2C interface
MQ2 mq2(MQ2_SENSOR_PIN);
TFT_eSPI tft = TFT_eSPI();
Touch_PCB01 touch;
Adafruit_NeoPixel leds(NUMBER_LEDS, LED_PIN, NEO_RGB + NEO_KHZ800);
//CRGB leds[NUMBER_LEDS];
RTC_DS3231 rtc;
JPEGDEC jpeg;
Adafruit_ADS1115 adc1;
Adafruit_ADS1115 adc2;
MoistureSensor sensors;
SelfCheckRoutine check;

// Watering Variables
const int wateringValue = 40;
bool watering = false;

// Display Variables
constexpr uint16_t SCREEN_WIDTH  = 320;
constexpr uint16_t SCREEN_HEIGHT = 240;

lv_color_t lvBuffer[SCREEN_WIDTH * 20]; // Buffer

lv_disp_draw_buf_t drawBuffer;
lv_disp_drv_t displayDriver;

lv_indev_drv_t touchDriver; // Touch Driver

lv_obj_t* counterLabel = nullptr;


void setup() {
    Serial.begin(115200);
    delay(500);

    Serial.println();
    Serial.println("Start Programm: 'PlantWatering BreadBoard_Code'");
    Serial.println();

    // GPIO
    pinMode(BUTTONS, INPUT);
    pinMode(LED_PIN, OUTPUT);
    pinMode(MQ2_SENSOR_PIN, INPUT);

    pinMode(CS_SD, OUTPUT);
    digitalWrite(CS_SD, HIGH);

    pinMode(TFT_CS, OUTPUT);
    digitalWrite(TFT_CS, HIGH);
    analogReadResolution(10);

    //check.completeSelfCheck();
    check.selfCheck_wo_I2C();

    jpeg.setPixelType(RGB565_BIG_ENDIAN);

    createGUI();
}


void loop() {
  /*Touch_PCB01::Point p;

    if (touch.getPoint(p)) {
        Screensaver();
    }

    delay(10);*/
  static uint32_t lastTick = millis();

  uint32_t now = millis();

  // LVGL mitteilen, wie viel Zeit vergangen ist
  lv_tick_inc(now - lastTick);

  lastTick = now;


  // LVGL abarbeiten
  lv_timer_handler();


  delay(5);
}

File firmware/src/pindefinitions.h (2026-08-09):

#include "lvgl.h"
#ifndef PIN_DEFINITIONS
#define PIN_DEFINITIONS

// Display constances
const uint16_t BLUE = 0x4d13;
const uint16_t GREEN = 0x2e4c;
const uint16_t RED = 0xfc00;

#define MARGIN_LEFT 10
const int linespace = 20;


// Watering Variables
extern const int wateringValue;
extern bool watering;

// Display Variables
extern const uint16_t SCREEN_WIDTH;
extern const uint16_t SCREEN_HEIGHT;

extern lv_color_t lvBuffer[];
extern lv_disp_draw_buf_t drawBuffer;
extern lv_disp_drv_t displayDriver;
extern lv_indev_drv_t touchDriver;
extern lv_obj_t* counterLabel;


// Time Info
/*
const char* ntpServer = "pool.ntp.org";
const long  gmtOffset_sec = 3600;
const int   daylightOffset_sec = 3600;
*/

// ********** I2C Pins *********
#ifndef I2C_SCL
#define I2C_SCL 22
#endif

#ifndef I2C_SDA
#define I2C_SDA 21
#endif

#ifndef ADDR_ADC1
#define ADDR_ADC1 0x48
#endif

#ifndef ADDR_ADC2
#define ADDR_ADC2 0x49
#endif

#ifndef ADDR_CLOCK1
#define ADDR_CLOCK1 0x57 
#endif

#ifndef ADDR_CLOCK2
#define ADDR_RTC 0x68 
#endif

#ifndef ADDR_BMP280
#define ADDR_BMP280 0x76
#endif

#ifndef ADDR_BMP180
#define ADDR_BMP180 0x77
#endif


// ********* SPI Pins *********
#ifndef MOSI
#define MOSI 23
#endif

#ifndef MISO
#define MISO 19
#endif

#ifndef SCL_SPI
#define SCL_SPI 18
#endif

#ifndef CS_SD
#define CS_SD 5
#endif


// ********* Analog Signal Pins ********
#ifndef MQ_SENSOR_PIN
#define MQ2_SENSOR_PIN 34 // Analog 9
#endif

#ifndef ANALOG10
#define ANALOG10 35 // Display Touch
#endif

#ifndef BUTTONS 
#define BUTTONS 36 // Analog 11
#endif

#ifndef ANALOG12
#define ANALOG12 39 // Display Touch
#endif


// ******** LCD Display Pins ******** //actually they're configured in .pio\libdeps\az-delivery-devkit-v4\TFT_eSPI\User_Setups. It's just for clarification :)
#ifndef LCD_Pins 

    // Control Pins
    #define TFT_CS   33
    #define TFT_DC   15   // LCD_RS
    #define TFT_RST  -1
    #define TFT_WR    4
    #define TFT_RD   -1

    // 8-Bit-Databus
    #define TFT_D0   12
    #define TFT_D1   13
    #define TFT_D2   26
    #define TFT_D3   25
    #define TFT_D4   17
    #define TFT_D5   16
    #define TFT_D6   27
    #define TFT_D7   14

#endif


// ********** LED Strip ********
#ifndef LED_PIN
#define LED_PIN 32
#endif

#ifndef NUMBER_LEDS
#define NUMBER_LEDS 8
#endif

#ifndef LED_TYPE
#define LED_TYPE WS2812B
#endif

#ifndef COLOR_ORDER
#define COLOR_ORDER RGB
#endif

#ifndef BRIGHTNESS
#define BRIGHTNESS 255
#endif

// ********** Screensaver Video ********
#ifndef SCREENSAVER_VIDEO_FILE_NAME
#define  SCREENSAVER_VIDEO_FILE_NAME "/Images/Lizard.mjpeg";
#endif


#endif

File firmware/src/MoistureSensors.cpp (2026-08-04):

#include <Arduino.h>
#include "functions.h"
#include "pindefinitions.h"
#include <Adafruit_ADS1X15.h>

extern Adafruit_ADS1115 adc1;
extern Adafruit_ADS1115 adc2;

int MoistureSensor::getSensorValue(int SensorID) {
        int value;
        switch(SensorID) {
            case 0:
                value = adc1.readADC_SingleEnded(0);
                return value;
            case 1:
                value = adc1.readADC_SingleEnded(1);
                return value;
            case 2:
                value = adc1.readADC_SingleEnded(2);
                return value;
            case 3:
                value = adc1.readADC_SingleEnded(3);
                return value;
            case 4:
                value = adc2.readADC_SingleEnded(0);
                return value;
            case 5:
                value = adc2.readADC_SingleEnded(1);
                return value;
            default:
                Serial.println("SensorID out of Range");
                return 120;
        }
    }

void MoistureSensor:: printSensorData(int SensorID) {
        Serial.printf("Sensor-%d Value: %4d \n", SensorID+1, getSensorValue(SensorID));
    }

void MoistureSensor:: printSensorData(void) {
        for (int i = 0; i<6; i++) {
            Serial.printf("Sensor-%d Value: %4d \n", i+1, getSensorValue(i));
            delay(100);
        }
    }

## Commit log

2026-06-15 changed pin configuration so now display and leds work fine
2026-06-15 added MQ2-Sensor
2026-06-26 added buttons and interrupts
2026-06-26 added the pcb files from other directory
    [PCB_PlantWatering.kicad_pcb, PCB_PlantWatering.kicad_sch, PlantWatering_PCB01.kicad_pcb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]
2026-06-27 added readme text
    [PCB_PlantWatering.kicad_pcb, PCB_PlantWatering.kicad_sch]
2026-06-28 changed PCB01
    [PlantWatering_PCB01.csv, PlantWatering_PCB01.kicad_pcb, PlantWatering_PCB01.kicad_sch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]
2026-06-28 modified PCB02 for 2Layer board in order to save money
    [PlantWatering_PCB02.kicad_pcb, bom.csv, positions.csv]
2026-06-28 update PDF and added labels to PCB02
    [PCB_PlantWatering.kicad_pcb, PlantWatering_PCB02.kicad_pcb]
2026-06-29 changed resistance of buttons (look at schematic)
    [PlantWatering_PCB01.kicad_pcb, PlantWatering_PCB01.kicad_sch, bom.csv]
2026-06-29 cleaned up button code
2026-07-01 added the solar panel and I2C Analog extender
2026-07-05 added main pwr switch to pcb01
    [PlantWatering_PCB01.kicad_pcb, PlantWatering_PCB01.kicad_sch]
2026-07-05 made ready for hackclub
    [PCB_PlantWatering.kicad_pcb, PCB_PlantWatering.kicad_sch, PlantWatering_PCB01.csv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]
2026-07-05 changed project structure
    [PlantWatering_PCB01.csv, PlantWatering_PCB01.kicad_sch]
2026-07-05 changed structure
    [PCB_PlantWatering.kicad_pcb, PCB_PlantWatering.kicad_sch, PlantWatering_PCB01.csv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]
2026-07-05 changed structure and added cart
    [PCB_PlantWatering.kicad_pcb, PCB_PlantWatering.kicad_sch, PlantWatering_PCB02.csv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]
2026-07-07 added Assembly
    [PCB01.step, PCB02.step, SmartIrrigationSystem-Assembly.step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]
2026-07-07 added Global BOM and changed smaller things at the README/Journal
    [GlobalBOM.csv]
2026-07-07 changes readme and Journal
    [PCB_PlantWatering.kicad_pcb, PCB_PlantWatering.kicad_sch]
2026-07-07 added BOM
    [BOM.csv]
2026-07-07 added assembly photo
2026-07-09 some improvements in order to make it cheaper (affordable)
    [PlantWatering_PCB02.csv, PlantWatering_PCB02.kicad_sch, SmartIrrigationSystem.FCStd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]
2026-07-09 final state before ordering
    [PlantWatering_PCB01.kicad_pcb, PlantWatering_PCB01.kicad_sch, PlantWatering_PCB02.kicad_pcb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]
2026-07-17 I ordered it!!!!!
    [PlantWatering_PCB01.csv, PlantWatering_PCB01.kicad_sch, bom.csv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]
2026-07-29 changed cp2102
    [bom.csv]
2026-08-02 fixed some bugs in selfchecking routine
    [main.cpp]
2026-08-03 corrected the selfchecking routine. got errors, have problems with power, dont get the leds light up
    [main.cpp, pindefinitions.h]
2026-08-03 I2C progress
2026-08-03 last changes before trying to get I2C by removing everythin... which me luck
2026-08-03 fixed I2C
2026-08-04 fixed SD idk how
    [main.cpp]
2026-08-04 changed ads to adc
2026-08-04 added moisture Sensor read class
2026-08-08 fixed errors and fitted my functions
    [data_capture.cpp, main.cpp, pindefinitions.h]
2026-08-08 added selfcheck bmp- that broke i2c
    [data_capture.cpp, main.cpp, pindefinitions.h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]
2026-08-08 it is a hardware problem with a lose GND connection to PCB02...
    [main.cpp, pindefinitions.h]
2026-08-09 added selfcheck wo i2c and fixed variable declaration of watering variables
    [data_capture.cpp, main.cpp, pindefinitions.h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]
2026-08-09 added touch display code with some use of AI- screensaver with touch interrupt
2026-08-09 working button counter
2026-08-29 fusion of PCBs schematic. added esp32S3_16mb chip to schematic. added PWR_Regulator according to https://dl.espressif.com/dl/schematics/SCH_ESP32-C5-DevkitC-1_V1.2_20250211.pdf
    [SinglePCBPlantWatering.kicad_pcb, SinglePCBPlantWatering.kicad_sch]
2026-10-11 added Schematic PCB
2026-10-11 set footprints, added TestPoints, searched JLCPCB Parts
2026-10-13 added battary voltage measurement and one more MS. selected footrints using easyeda2kicad and mapped the correct jlcpcb part number- need to find right connectors. worked about 2 hours
2026-10-20 layout of the pcb - wiring without gnd and power plane
2026-10-21 added 3D models to the parts and modified shape of pcb
2026-10-24 added decoupling capacitors
2026-10-24 changed pcb color, fixed design misakes (DRC), made new edge cuts, exported new image of the pcb
2026-10-25 solved warnings from drc and menaged silkscreen
2026-10-26 first gerber files, last polish
2026-10-28 fpc connector was in the wrong orientation. I moved it to the front, made a hole into the pcb, reorganized the libraries, rerouted everything, removed the unnecessary I2C outputs, rearranged componen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
2026-10-28 moved silkscreen and replaced buttons with smd ones
2026-10-29 3d printed a scaled model of it, had to move the USBC closer to edge, rerouted, made hole for fpc wider, saved 40$ while placing all components on one side, time spend for this commit: 2h
2026-11-04 added breakout part to enlarge surface and make pcba economic possible. got into troble with led pwm. probably should change display interface from 8bit parallel to spi. will do that in development b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
